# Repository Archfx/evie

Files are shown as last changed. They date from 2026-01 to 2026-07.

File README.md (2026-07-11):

# Camaro6 CAD files
### EVIE is my 6<sup>th</sup> gen Camaro

This repository contains various CAD models I have designed for 6th-generation Camaros built on the [alpha platform](https://en.wikipedia.org/wiki/General_Motors_Alpha_platform). 
These models were created using [FreeCAD](https://www.freecad.org/) and [KiCad](https://www.kicad.org/). 

Electric Vacuum Pump
---

The mount is designed for installing the GM electric vacuum pump from the C7 Corvette onto 6th-generation LTG Camaros. It attaches directly to the existing bolt holes in the passenger-side engine compartment, next to the downpipe. No additional drilling is required.

 <p align="center">
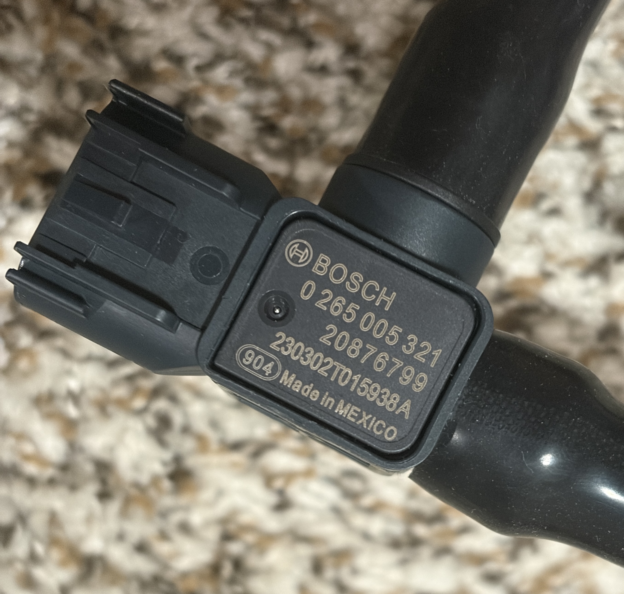
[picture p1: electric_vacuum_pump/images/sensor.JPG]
  
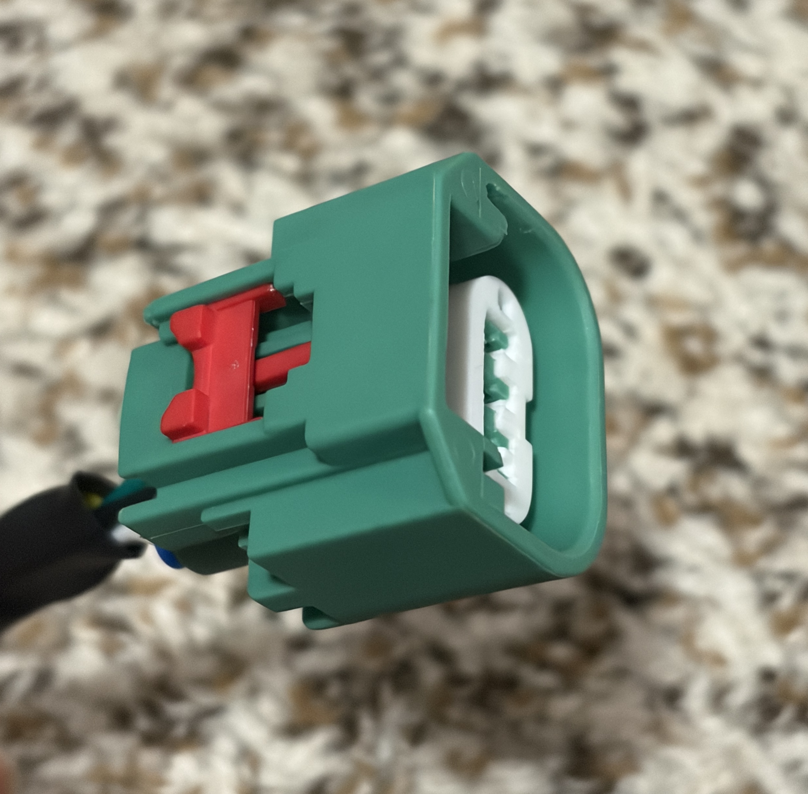
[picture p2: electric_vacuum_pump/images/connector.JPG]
  
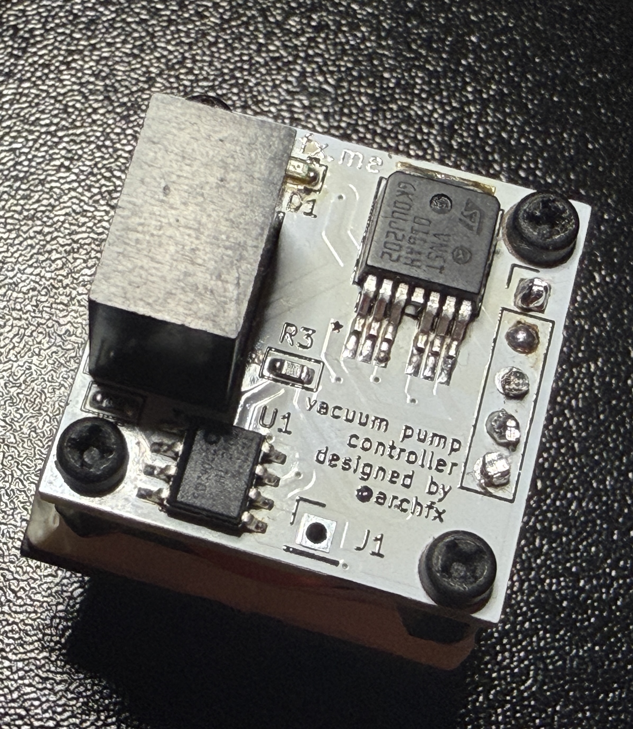
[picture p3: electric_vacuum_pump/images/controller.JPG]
  
</p>

Fire Extinguisher Mount
---

This directly mounts to the rear rails of the passenger seat. 

 <p align="center">
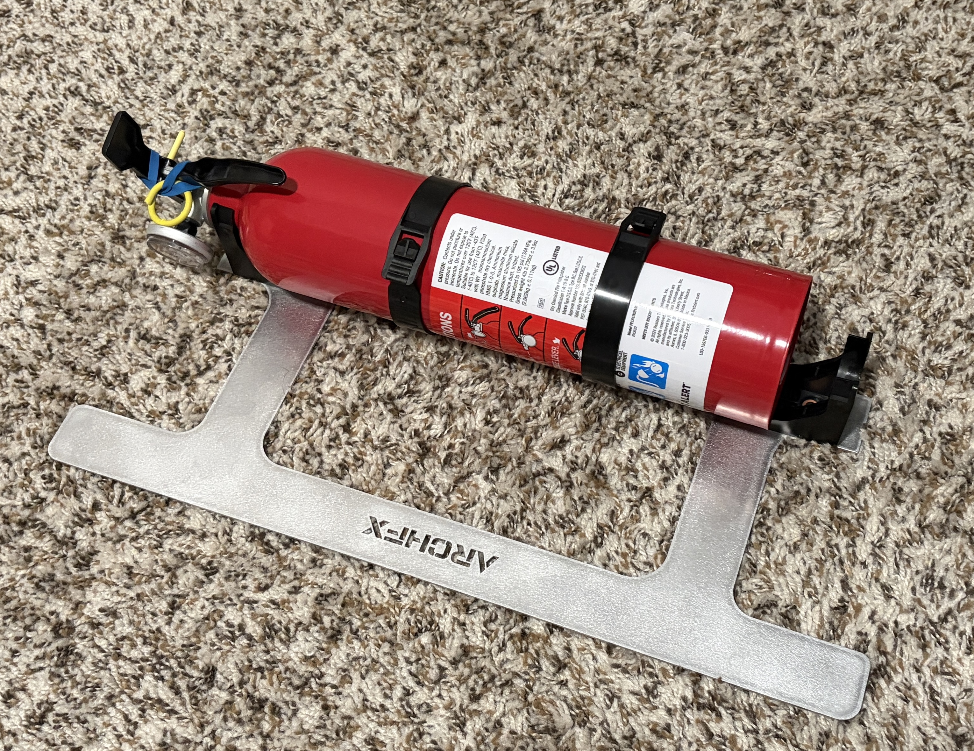
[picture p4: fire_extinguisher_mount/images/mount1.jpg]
  
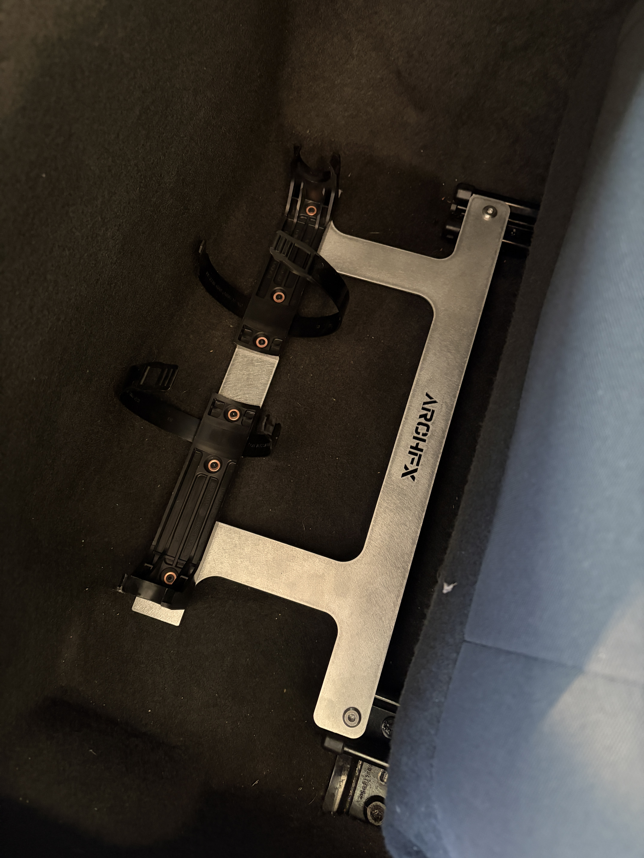
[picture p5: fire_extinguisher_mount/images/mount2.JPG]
  
</p>

<p align="center">
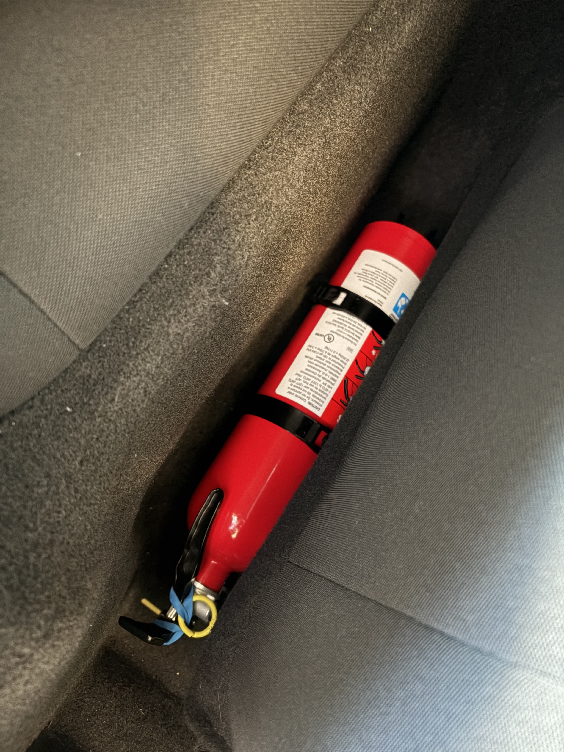
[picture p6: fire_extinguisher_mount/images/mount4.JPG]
  
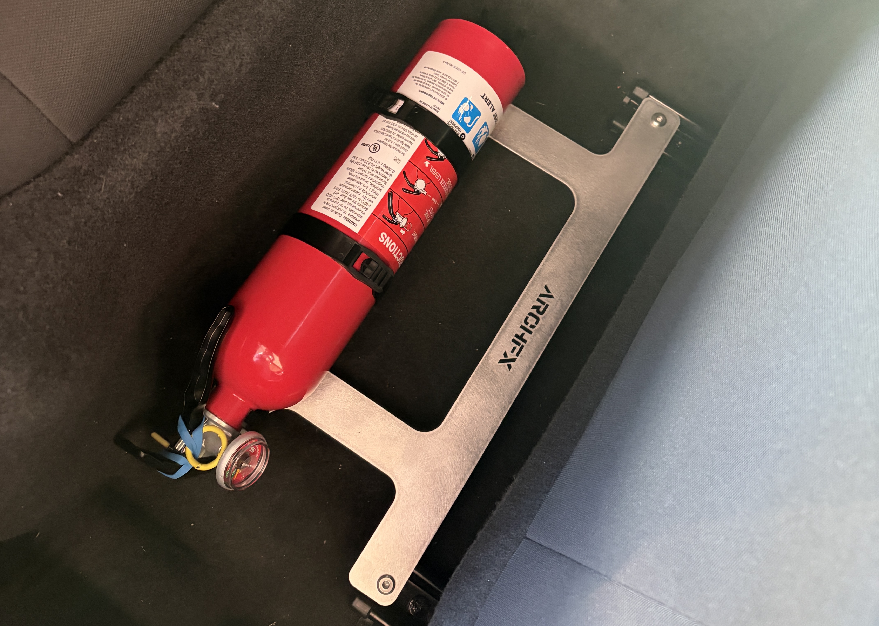
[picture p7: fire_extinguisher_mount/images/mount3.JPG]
  
</p>

Assembly Requires the Following Items:
- Fire extinguisher and the mounting bracket (I used a [First Alert](https://www.firstalert.com/))
- Mounting hardware for the bracket
- 2x 6mm steel standoff (24mm height)
- 2x 6mm hex nut and bolt
- Drill

Note: You may need to slightly enlarge the left rail bolt hole to accommodate a 6 mm standoff. Alternatively, a 5 mm standoff can be used without any modification.

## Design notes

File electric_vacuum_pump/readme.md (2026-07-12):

Relay Box Parts
----

- CID101-2.8-FS4 Original Yazaki 7116-4153-02 Terminal, YESC 2.8 mm, Female, 3.0 - 4.0 mm² × 2

- MTA 0301504 MiniVAL / Mini Relay Gray Module × 1

- CID101-2.8-MS4 Original Yazaki 7114-4153-02 Terminal , Male, 3.0 - 4.0 mm² × 4

- MTA 1708332-L Mini 280 Female Terminal, Unsealed, 2.5 - 4.0 mm² × 4

- MTA 1708500-L Female Terminal, 630 Series, Unsealed, 0.35 - 0.5 mm² × 8

- MTA 1708502-L Female Terminal, 630 Series, Unsealed, 2.0 - 3.0 mm² × 6

- MTA 0301506 Secondary Lock for 0301504 Gray Module × 1

- CID203-2.3-FS1 Drop In for Sumitomo 1500-0106 Sealed Female 090 Terminals, 0.3 -0.5 mm², Tin Plated × 5

- CID2026J-2.3-21 Drop In for Sumitomo 2-way Sealed Female MT090 Connector 6180-2327, Light Gray × 2

- CID203-2.3-MS2 Drop In for Sumitomo 1500-0105 Male Terminal 090, 0.85 - 1.25 mm², Tin Plating × 5

- CID2026J-2.3-11 Drop In for Sumitomo 2-way Sealed Male MT090 Connector 6187-2317, Light Gray × 2

- MAH-S-112-C-1D2 ISO Mini Relay 60A, 12Vdc, SPDT with Diode Suppression Drop in for Song Chuan 896H-1CH-C-002-12VDC × 1

- MTA 0301590 Cover for a Single Gray Module × 1

- MTA 0301580 Mounting Bracket for Gray Modules × 2

- MTA 0705160 MiniVAL 25 Amp Fuse, White × 3

- CID3110 Original Yazaki 7158-3110-40 Wire Seal, YESC 2.8 mm, Gray, Silicone × 4

- CID101-2.8-MS4 Original Yazaki 7114-4153-02 Terminal , Male, 3.0 - 4.0 mm² × 4

Controller PCB Parts
---

| Id | Designator | Footprint | Quantity | Designation |
|----|---|---|---|---|
| 1  | U3 | HPAK_16AH-E_STM | 1 | VN5T016AHTR-E |
| 2  | LED1 | LED_0603_1608Metric | 1 | LED_0603 |
| 3  | U2 | Converter_DCDC_TRACO_TSR1-xxxxE_THT | 1 | TSR1-2450E |
| 4  | R3 | R_0603_1608Metric | 1 | 1K_R_0603 |
| 5  | R5 | R_0603_1608Metric | 1 | 1k |
| 6  | J1 | PinHeader_1x01_P2.54mm_Vertical | 1 | Program |
| 7  | J2 | PinHeader_1x05_P2.54mm_Vertical | 1 | Mini Relay Pins |
| 8  | U1 | SOIC-8_3.9x4.9mm_P1.27mm | 1 | ATtiny412-SS |
| 9  | C4,C5 | C_0603_1608Metric | 2 | 10nf |
| 10 | R2,R4,R7 | R_0603_1608Metric | 3 | 56K |
| 11 | FB1 | C_0603_1608Metric | 1 | BLM18PG121SN1D  |
| 12 | C1 | C_1812_4532Metric | 1 | 22uf |
| 13 | R6 | R_0603_1608Metric | 1 | 10R |
| 14 | C6,C3 | C_0603_1608Metric | 2 | 100nf |
| 15 | R8,R1 | R_0603_1608Metric | 2 | 100K |
| 16 | D1 | D_SMB | 1 | SMBJ24A-Q |
| 17 | D3 | D_SOD-323 | 1 | PESD5V0S1BA |
| 18 | C2 | C_1210_3225Metric | 1 | 10uf |

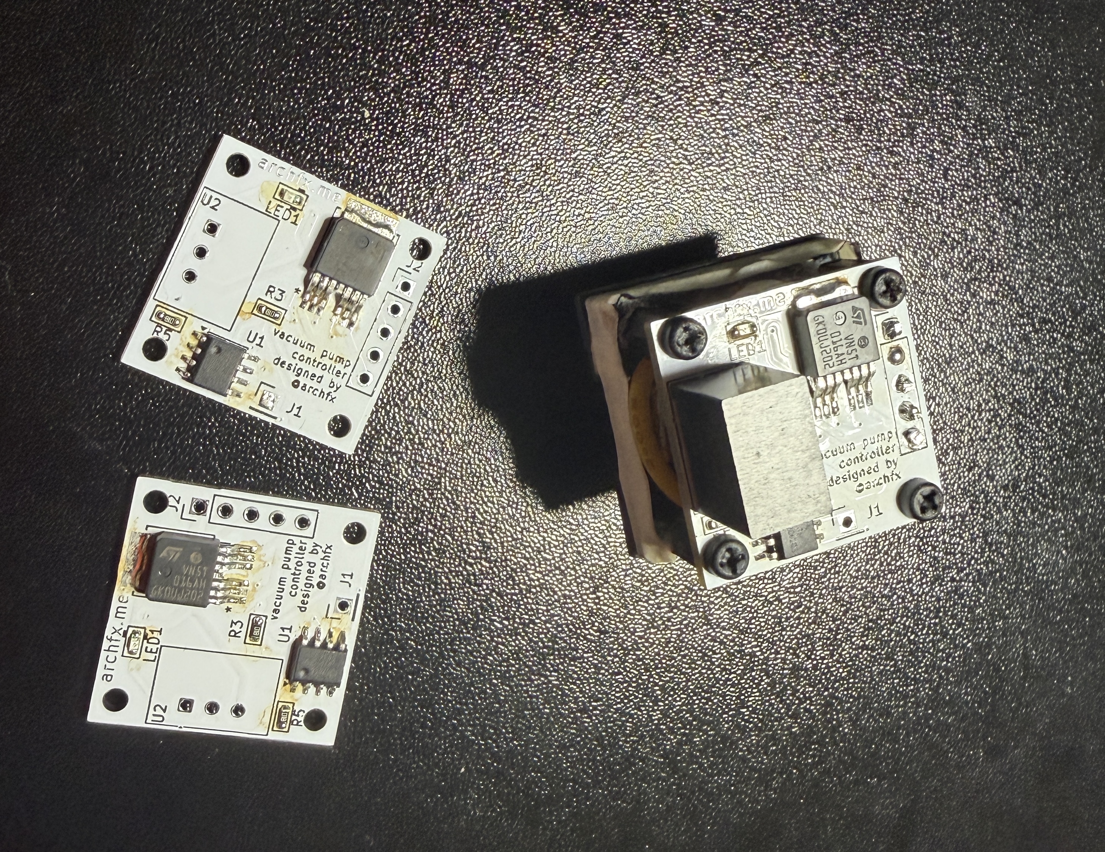
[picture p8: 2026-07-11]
electric_vacuum_pump/images/wip.JPG

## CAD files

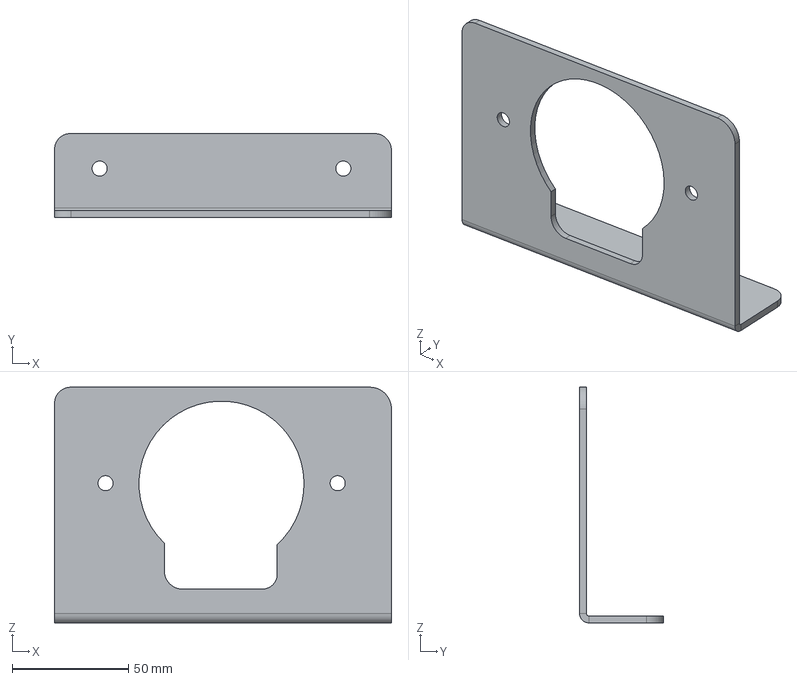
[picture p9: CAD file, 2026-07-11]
electric_vacuum_pump/mount/vacuum_pump_mnt_v2-BodyFold.step
145.2 x 36.2 x 101.5 mm

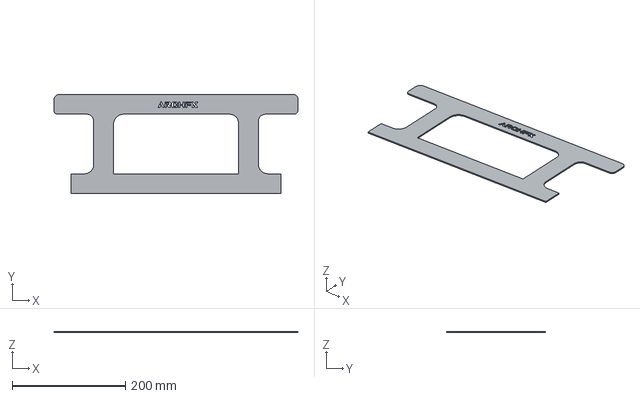
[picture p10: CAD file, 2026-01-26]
fire_extinguisher_mount/ext_mount-Body.step
430.0 x 175.0 x 2.00 mm

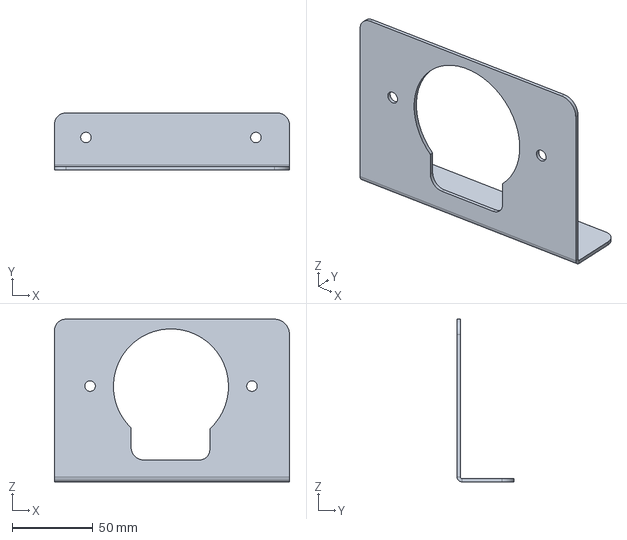
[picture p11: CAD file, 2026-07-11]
electric_vacuum_pump/mount/vacuum_pump_mnt_v2.FCStd
145.2 x 35.2 x 100.5 mm

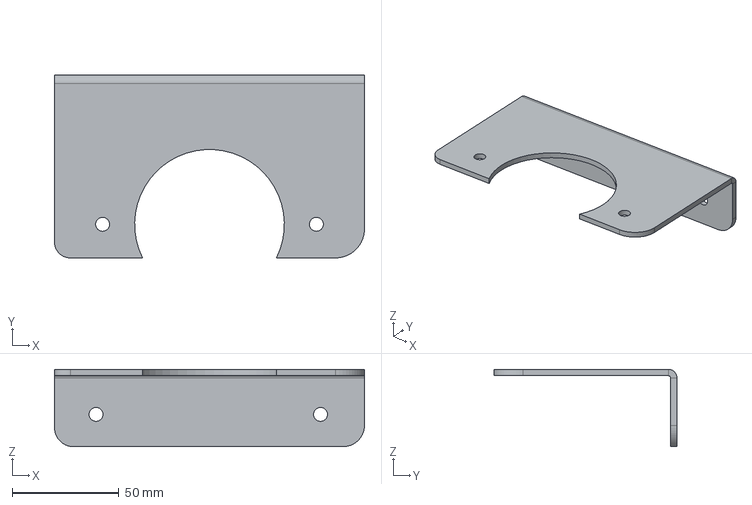
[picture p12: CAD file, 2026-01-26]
electric_vacuum_pump/mount/vacuum_pump_mnt_v1-Body.step
145.0 x 85.5 x 36.2 mm

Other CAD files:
electric_vacuum_pump/mount/ImageToStl.com_vacuum_pump_mnt_v2-2mm.stl
electric_vacuum_pump/mount/vacuum_pump_mnt_v2-2mm.step
electric_vacuum_pump/mount/old_mount/vacuum_pump_mnt_v1.FCStd
electric_vacuum_pump/mount/vacuum_pump_mnt_v1.FCStd
electric_vacuum_pump/mount/old_mount/vacuum_pump_mnt_v1-Body.stl
electric_vacuum_pump/mount/vacuum_pump_mnt_v1-Body.stl
fire_extinguisher_mount/ext_mount-Body.FCStd
fire_extinguisher_mount/ext_mount-Body.stl

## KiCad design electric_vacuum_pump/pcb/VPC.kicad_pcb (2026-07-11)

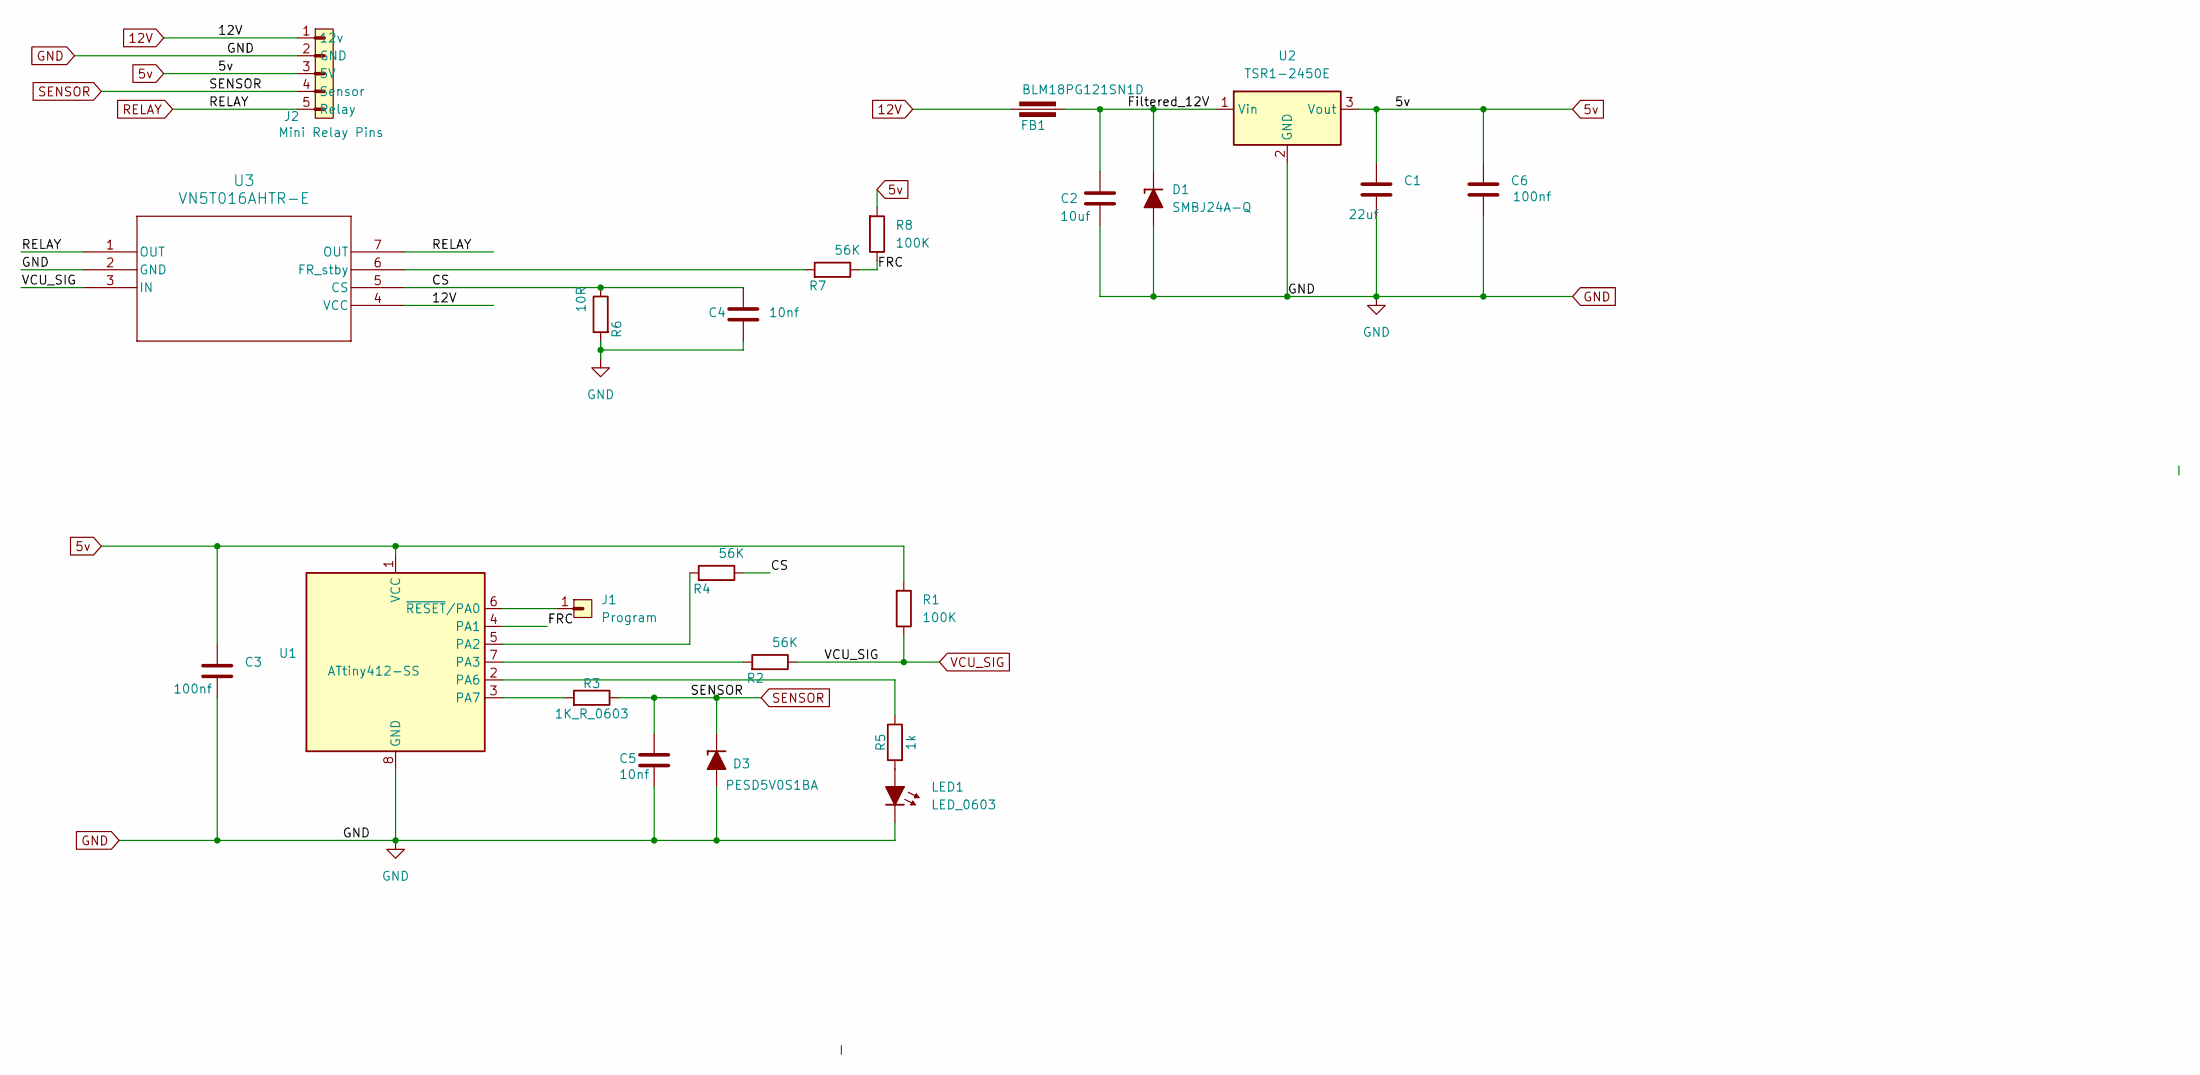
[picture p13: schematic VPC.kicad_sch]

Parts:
C1: 22uf; C_1812_4532Metric
C2: 10uf; C_1210_3225Metric
C3, C6: 100nf; C_0603_1608Metric
C4, C5: 10nf; C_0603_1608Metric
D1: SMBJ24A-Q; D_SMB
D3: PESD5V0S1BA; D_SOD-323
FB1: BLM18PG121SN1D; C_0603_1608Metric
J1: Program; PinHeader_1x01_P2.54mm_Vertical
J2: Mini Relay Pins; PinHeader_1x05_P2.54mm_Vertical
LED1: LED_0603; LED_0603_1608Metric
R1, R8: 100K; R_0603_1608Metric
R2, R4, R7: 56K; R_0603_1608Metric
R3: 1K_R_0603; R_0603_1608Metric
R5: 1k; R_0603_1608Metric
R6: 10R; R_0603_1608Metric
U1: ATtiny412-SS; SOIC-8_3.9x4.9mm_P1.27mm
U2: TSR1-2450E; Converter_DCDC_TRACO_TSR1-xxxxE_THT
U3: VN5T016AHTR-E; HPAK_16AH-E_STM

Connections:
5v: C1.1, C3.1, C6.1, J2.3 (5V), R1.1, R8.1, U1.1 (VCC), U2.3 (Vout)
12V: FB1.2, J2.1 (12v), U3.4 (VCC)
/CS: C4.1, R4.2, R6.2, U3.5 (CS)
/FRC: R7.2, R8.2, U1.4 (PA1)
/Filtered_12V: C2.2, D1.1 (K), FB1.1, U2.1 (Vin)
GND: C1.2, C2.1, C3.2, C4.2, C5.2, C6.2, D1.2 (A), D3.2 (A), J2.2 (GND), LED1.1 (K), R6.1, U1.8 (GND), U2.2 (GND), U3.2 (GND)
unnamed: LED1.2 (A), R5.1
unnamed: R4.1, U1.5 (PA2)
unnamed: R2.1, U1.7 (PA3)
unnamed: R5.2, U1.2 (PA6)
unnamed: R3.1, U1.3 (PA7)
unnamed: J1.1, U1.6 (~RESET/PA0)
unnamed: R7.1, U3.6 (FR_stby)
RELAY: J2.5 (Relay), U3.1 (OUT), U3.7 (OUT)
SENSOR: C5.1, D3.1 (K), J2.4 (Sensor), R3.2
VCU_SIG: R1.2, R2.2, U3.3 (IN)

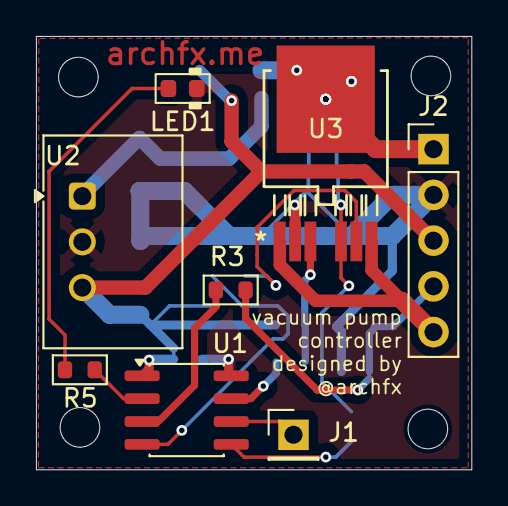
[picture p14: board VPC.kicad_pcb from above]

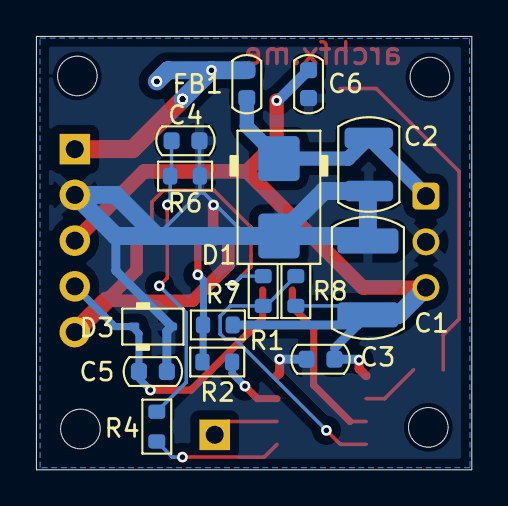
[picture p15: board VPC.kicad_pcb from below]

Board: 2 copper layers, 24.2 x 24.1 mm, 23 parts (15 on the bottom side), 16 nets.

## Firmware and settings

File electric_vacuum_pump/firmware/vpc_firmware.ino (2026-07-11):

// ATtiny412 (megaTinyCore)
// PA7 = analog input (vacuum sensor)
// PA6 = LED indicator
// PA3 = relay control (HIGH = pump ON)

const uint8_t LED_PIN    = PIN_PA6;
const uint8_t RELAY_PIN  = PIN_PA3;
const uint8_t SENSOR_PIN = PIN_PA7;

// Hysteresis thresholds
const int START_ADC = (int)(3.1f / 5.0f * 1023.0f + 0.5f);
const int STOP_ADC  = (int)(3.5f / 5.0f * 1023.0f + 0.5f);

// Timing protections
const uint32_t MIN_ON_TIME_MS  = 3000;
const uint32_t MIN_OFF_TIME_MS = 1000;

// Sensor fault limits
const int SENSOR_MIN = 10;
const int SENSOR_MAX = 1013;

enum PumpState {
  PUMP_OFF,
  PUMP_ON,
  FAULT
};

PumpState state = PUMP_OFF;

uint32_t stateChangeTime = 0;

int readFilteredSensor() {

  const int samples = 8;
  long sum = 0;

  for (int i = 0; i < samples; i++) {
    sum += analogRead(SENSOR_PIN);
  }

  return sum / samples;
}

void setPump(bool on) {

  digitalWrite(RELAY_PIN, on ? HIGH : LOW);
  digitalWrite(LED_PIN, on ? HIGH : LOW);

  stateChangeTime = millis();
}

void startupBlink() {

  digitalWrite(LED_PIN, HIGH);
  delay(80);
  digitalWrite(LED_PIN, LOW);
  delay(80);

  digitalWrite(LED_PIN, HIGH);
  delay(180);
  digitalWrite(LED_PIN, LOW);
}

void setup() {

  pinMode(LED_PIN, OUTPUT);
  pinMode(RELAY_PIN, OUTPUT);

  startupBlink();

  setPump(false);

  delay(2000); // allow sensor to stabilize
}

void loop() {

  int sensor = readFilteredSensor();
  uint32_t now = millis();

  // Detect sensor fault
  if (sensor < SENSOR_MIN || sensor > SENSOR_MAX) {
    state = FAULT;
  }

  switch (state) {

    case PUMP_OFF:

      if (sensor < START_ADC) {

        setPump(true);
        state = PUMP_ON;
      }

      break;

    case PUMP_ON:

      // If vacuum drops again, reset timer
      if (sensor < START_ADC) {
        stateChangeTime = now;
      }

      // Only stop if condition is continuously satisfied
      if (sensor > STOP_ADC &&
          (now - stateChangeTime) > MIN_ON_TIME_MS) {

        setPump(false);
        state = PUMP_OFF;
      }

      break;

    case FAULT:

      // Fail-safe: run pump continuously
      setPump(true);

      break;
  }

  delay(10);
}

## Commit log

2026-01-26 cad files added
    [ext_mount-Body.FCStd, ext_mount-Body.step, ext_mount-Body.stl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]
2026-07-11 update with the latest mount
    [ImageToStl.com_vacuum_pump_mnt_v2-2mm.stl, vacuum_pump_mnt_v1-Body.step, vacuum_pump_mnt_v1-Body.stl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]
